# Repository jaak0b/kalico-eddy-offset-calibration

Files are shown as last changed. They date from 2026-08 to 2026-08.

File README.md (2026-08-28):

# eddy_tool_calibration 

A Kalico and Klipper plugin that accurately measures per-tool XYZ nozzle offsets on a toolchanger, even when the nozzle is dirty.

Uses a bed-mounted LDC1612 eddy-current coil (e.g. BTT Eddy Coil/Duo/USB or a Cartographer flashed with Klipper firmware).

A calibration run on my printer (https://www.youtube.com/watch?v=lr-eFiMrt0E)

## What you need

- A toolchanger running Kalico or Klipper.
- An LDC1612 board (e.g. BTT Eddy Coil/Duo/Usb or Cartographer flashed with Klipper firmware) mounted to the bed, coil facing up.
- For Z offsets: a contact switch (sexbolt, sexball, any fixed Z endstop).
- Your own toolchange and offset-apply gcode to change tools and apply offsets. This plugin is universal and it is not targeting any specific toolchange plugin.

## How accurate is it?

These numbers come from my printer, a Voron 2.4 with StealthChanger and a BTT
Eddy Coil, measured with `EDDY_REPEATABILITY`.

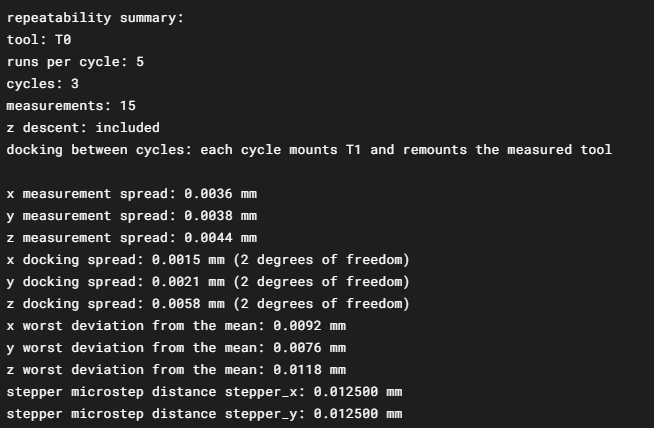
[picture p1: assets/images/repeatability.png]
Screenshot of EDDY_REPEATABILITY output


## Getting started

1. Wire up the eddy coil. See your probe's manual.
2. Mount the Eddy Coil Sensor to the bed with the coil facing up. [BTT Eddy Mount.stl](BTT%20Eddy%20Mount.stl) can be used for BTT Eddy probes.
3. Install the plugin, see [Install](#install).
4. Add the config, see [Required](#required).
5. Run [`EDDY_QUERY`](#commands) to check the wiring before anything moves.
6. Run [`LDC_CALIBRATE_DRIVE_CURRENT CHIP=eddy_tool_calibration`](#sensor-hardware). Only needed on non-BTT EDDY boards.
7. Jog the nozzle over the coil until the paper drags on the coil top face,
   then put the X, Y and Z position into `coil_x`, `coil_y` and
   `coil_z`.
8. Run [`EDDY_LOCATE`](#commands), and put the values into `coil_x` and `coil_y`.
9. For Z offsets (Optional): jog the nozzle over the contact switch (Sexball, Sexbolt or any other fixed mounted z homing switch), put those values
   into `switch_x`, `switch_y` and `switch_probe_z_start`, and set
   `calibrate_z: True`.
10. For Z offsets (Optional): Run [`EDDY_CALIBRATE_Z`](#commands) once per tool. Rerun it after a nozzle change.
11. Run [`EDDY_CALIBRATE_OFFSET`](#commands).
12. Run [`EDDY_REPEATABILITY T=0 RUNS=5 CYCLES=3`](#commands) to check the
    numbers are stable.

## Install

Requires Kalico or stock Klipper v0.13.0 or newer, an LDC1612 board
reachable over I2C (e.g. BTT Eddy Coil/Duo/Usb or Cartographer flashed with Klipper firmware) and Python 3 with no third-party packages.

```
cd ~
git clone https://github.com/jaak0b/kalico-eddy-offset-calibration
sh ~/kalico-eddy-offset-calibration/install.sh
sudo service klipper restart
```

Update manager entry for moonraker.conf:

```
[update_manager eddy_tool_calibration]
type: git_repo
path: ~/kalico-eddy-offset-calibration
origin: https://github.com/jaak0b/kalico-eddy-offset-calibration
primary_branch: main
is_system_service: False
```

## Config reference

Uncommented options are required and have no default, everything commented out may be left out. The blocks below are all parts of the same `[eddy_tool_calibration]` section.

### Required

```
[eddy_tool_calibration]
i2c_software_scl_pin:
i2c_software_sda_pin:
#   The SCL and SDA pins of the software i2c bus the LDC1612 chip is wired
#   to. This parameter must be provided.
coil_x:
coil_y:
#   Approximate machine X and Y (in mm) of the coil center. This parameter
#   must be provided.
coil_z:
#   Machine Z (in mm) of the coil top face. This parameter must be
#   provided.
coil_inner_diameter:
#   Bore (in mm) of the sensing coil. Must be greater than 0. It sets the
#   default fit_window_radius and scan_length. This parameter must be
#   provided.
```

### Toolchanger

Both tool_count and toolchange_gcode are needed only to run a calibration
command without T=. With toolchange_gcode set, both calibration commands
mount the tool they are about to work on, with T= as well as without it;
without it they work on whatever tool is already mounted. Every
non-baseline result is passed through apply_offsets_gcode as the run
proceeds.

```
#tool_count:
#   The number of tools on the machine, 1 to 16. Tools are T0 through
#   T(tool_count-1) with no gaps.
#toolchange_gcode:
#   The gcode that mounts a tool, as a template with {tool} bound to the
#   tool number.
#apply_offsets_gcode:
#   The gcode that applies a measured offset, as a template with {tool},
#   {offset_x} and {offset_y} bound, and {offset_z} bound as well when
#   calibrate_z is True. The default is to only report the offsets.
#tool_extruders:
#   Comma separated heater section names, one per tool, in tool number
#   order. Names are resolved at startup, so a name that does not exist is
#   a startup error. The default is to assume T0 uses extruder, T1 uses
#   extruder1 and so on.
```

### Z offset via the contact switch

> [!NOTE]
> Z offset means a tool's nozzle offset in Z relative to T0.

> [!IMPORTANT]
> The options below `calibrate_z` are ONLY required when `calibrate_z` is True.

> [!IMPORTANT]
> When `calibrate_z` is True, `EDDY_CALIBRATE_Z` must be run at least once, otherwise `EDDY_CALIBRATE_OFFSET` will refuse to measure the Z offset.

```
#calibrate_z: False
#   Set to True to measure Z. When set to True, `EDDY_CALIBRATE_Z` must be
#   run at least once.
#   The default is False.
switch_pin:
#   The endstop pin the contact switch is wired to. The switch itself is a plain
#   normally-open endstop switch; sexbolt and sexball style Z endstops work
#   well. The pin may be shared with an existing
#   [tools_calibrate] section.
#   This parameter must be provided.
switch_x:
#   The machine X position (in mm) the nozzle presses the switch at.
#   This parameter must be provided.
switch_y:
#   The machine Y position (in mm) the nozzle presses the switch at.
#   This parameter must be provided.
switch_probe_z_start:
#   The machine Z position (in mm) where each press starts from. Set it just above the
#   switch.
#   This parameter must be provided.
#switch_probe_speed: 5.0
#   Speed (in mm/s) of a downward press onto the switch. The default is
#   5.0mm/s.
#switch_probe_lift_speed:
#   Speed (in mm/s) of the retract between presses. The default is
#   switch_probe_speed.
#switch_probe_max_travel: 4.0
#   Distance (in mm) a press may travel down before the run is reported as
#   a missing trigger. The default is 4.0mm.
#switch_probe_sample_retract_dist: 2.0
#   Distance (in mm) the nozzle retracts after each press. Each press
#   starts from where the previous one retracted to, so this must be less
#   than switch_probe_max_travel. The default is 2.0mm.
#switch_probe_tolerance: 0.020
#   Distance (in mm) the three counted presses may disagree by before the
#   probing is reported as failed. The default is 0.020mm.
#calibration_temp: 150.0
#   Nozzle temperature (in Celsius) that every calibration measurement is
#   taken at. It must be above 0 when calibrate_z is True. The default is
#   150.0.
#calibration_temp_band: 2.0
#   Band (in Celsius) around the target temperature a nozzle has to read
#   within before the settle dwell starts. It applies both ways, so a tool
#   that has to cool only has to fall inside it. The default is 2.0.
#calibration_settle_time: 30.0
#   Dwell (in seconds) after a tool reaches the band, before measuring.
#   Both calibration commands dwell the same time, so both measure the
#   same thermal state. The default is 30.0 seconds.
#z_start: 2.5
#   Height (in mm) above the coil top face the downward Z move starts
#   from. The default is 2.5mm.
#z_stop: 0.5
#   Height (in mm) above the coil top face the downward Z move ends at.
#   Must be above the face, and below z_start. The default is 0.5mm.
#z_step: 0.05
#   Step size (in mm) of the downward Z move. Must be greater than 0, and
#   must divide the span from z_start to z_stop into a whole number of
#   steps. The default is 0.05mm.
```

### Sensor hardware

```
#i2c_address:
#i2c_mcu:
#i2c_bus:
#i2c_speed:
#   The remaining i2c settings for the LDC1612 chip. See the "common I2C
#   settings" section of Kalico's Config_Reference.md for a description of
#   these parameters. The chip's factory address is 42 decimal (0x2A).
#intb_pin:
#   The MCU gpio pin connected to the LDC1612 sensor's INTB pin, if it is
#   broken out. The default is to not use the INTB pin.
#frequency:
#   The external clock frequency (in Hz) fed to the LDC1612 CLKIN pin,
#   accepted from 2000000 to 40000000. It requires Kalico from March 2026,
#   or stock Klipper. The default is 12000000, which is correct for the
#   BTT Eddy family.
#reg_drive_current:
#   The LDC1612 DRIVE_CURRENT0 register value, 0 to 31. The default is 15,
#   which suits the BTT Eddy coil probe. For any other coil determine the right value with
#   `LDC_CALIBRATE_DRIVE_CURRENT CHIP=eddy_tool_calibration` and store the
#   printed value with SAVE_CONFIG. If a scan fails with a sensor
#   amplitude error ("Eddy current sensor error"), raise this value by one
#   and retry.
```

### Scan and fit tuning

```
#scan_height: 1.0
#   Height (in mm) above the coil top face the XY scan passes run at. Must
#   be above the face and below z_start. The default is 1.0mm.
#scan_safe_z: 2.0
#   Extra clearance (in mm) added above the scan height for travel moves.
#   Must be greater than 0. The default is 2.0mm.
#scan_speed: 4.0
#   Speed (in mm/s) of an XY scan pass. Lower it if a pass returns fewer
#   than samples_min samples. The default is 4.0mm/s.
#scan_length:
#   Length (in mm) of an XY scan pass. The default is 1.5 times
#   coil_inner_diameter: 12.0 mm for the 8 mm BTT Eddy Coil bore, 3.0 mm
#   for the 2 mm Little Crab bore.
#locate_scan_length:
#   Length (in mm) of the coarse EDDY_LOCATE pass. The default is three
#   times scan_length.
#travel_speed: 100.0
#   Speed (in mm/s) of XY travel moves between passes. The default is
#   100.0mm/s.
#z_speed: 10.0
#   Speed (in mm/s) of every Z leg except the switch presses, which use
#   switch_probe_speed and switch_probe_lift_speed. The default is
#   10.0mm/s.
#scan_angles: 45, 135
#   Comma separated scan directions (in degrees), where 0 runs along X+
#   and 90 along Y+. Two directions at least 30 degrees apart are needed
#   to get both axes. A repeated angle is a config error, and so is a pair
#   of opposite angles when pair_scans is enabled. The default is 45, 135.
#pair_scans: True
#   Set to True to scan the opposite of every configured angle as well and
#   average each pair, which cancels the shift each pass picks up along the
#   direction it travels. Pairing doubles the number of passes. The default
#   is True.
#samples_min: 100
#   Minimum usable samples per scan pass, at least 3. A pass below it is
#   reported as an error. The default is 100.
#query_time: 0.5
#   Time (in seconds) EDDY_QUERY collects samples for, at the driver's
#   250 Hz rate (400 Hz on Klipper master). The default is 0.5 seconds,
#   about 125 samples.
#freq_min: 1000000.0
#   Frequency (in Hz) below which samples are discarded as startup or
#   noise readings. The default is 1000000.0.
#edge_margin: 0.15
#   Fraction of each pass treated as its edge, above 0 and below 0.5. The
#   edges are left out of the search for the peak, and are used to tell
#   whether the pass peaks up or down. The default is 0.15.
#fit_window_radius:
#   Half width (in mm) of the sample window either side of the peak that
#   the curve is fitted to. The default is half of coil_inner_diameter.
#fit_sigma_fraction: 0.5
#   Standard deviation of the fit's weighting, as a fraction of the fit
#   window. It makes samples near the peak count for more than samples at
#   the window's edge. The default is 0.5.
#fit_vertex_limit: 0.5
#   Maximum distance between the fitted peak and the peak sample, as a
#   fraction of the fit window. A fit landing beyond it is reported as
#   failed rather than pulled back into range. The default is 0.5.
#center_tolerance: 0.05
#   Distance (in mm) two consecutive rounds of an XY measurement may
#   differ by before the measurement stops and reports the last round's
#   center. Rounds that differ by more are followed by another refine
#   round. Must be greater than 0. The default is 0.05mm.
#max_rounds: 6
#   Most scan rounds, counting the coarse round, one XY measurement runs
#   before it is reported as not settled. At least 2. The default is 6.
```

### Logging

```
#save_history: True
#   Set to True to append every completed measurement of a tool to
#   history_T<n>.csv in log_dir: the UTC timestamp, the command, the
#   fitted center, the offsets, the session of the baseline they were
#   measured against, the Z crossing and the height where the switch
#   clicks, the nozzle temperature the run was held at, the nozzle reading
#   observed while it ran, and the sample count. The default is True.
#save_csv: False
#   Set to True to write every scan pass's raw samples to a CSV file for
#   offline review. The default is False.
#log_dir: EddyToolCalibration/logs
#   Directory the drift logs and the repeatability study files are written
#   to, read against the printer config directory unless it is an absolute
#   path. These are the durable record. The default is
#   EddyToolCalibration/logs.
#csv_dir: EddyToolCalibration/data
#   Directory the raw scan dumps of save_csv are written to, read against
#   the printer config directory unless it is an absolute path. These are
#   working files, meant to be cleared once they have been looked at. The
#   default is EddyToolCalibration/data.
```

### Integration with Klipper Toolchanger plugin

Append the following config reference to `[eddy_tool_calibration]` for integration with [viesturz's klipper-toolchanger](https://github.com/viesturz/klipper-toolchanger)
```ini
toolchange_gcode:
    T{tool}
apply_offsets_gcode:
    SET_TOOL_PARAMETER T={tool} PARAMETER=gcode_x_offset VALUE={offset_x}
    SET_TOOL_PARAMETER T={tool} PARAMETER=gcode_y_offset VALUE={offset_y}
    SET_TOOL_PARAMETER T={tool} PARAMETER=gcode_z_offset VALUE={offset_z}
```

Append the following config reference to `[eddy_tool_calibration]` for integration with [klipper-toolchanger-hard](https://github.com/Contomo/klipper-toolchanger-hard)
```ini
toolchange_gcode:
    T{tool}
apply_offsets_gcode:
    SET_TOOL_OFFSET T={tool} X={offset_x} Y={offset_y} Z={offset_z}
```

## Supported hardware

Any eddy style probe with an LDC1612 works as long as it is flashed with stock Klipper firmware and reachable over I2C.

| Board |  |
|---|---|
| BTT Eddy Coil | Conected directly to the mainboard or a toolheadboard |
| BTT Eddy USB | Expected to work unmodified; I have not tried one. Its RP2040 runs standard Klipper firmware as a second MCU |
| BTT Eddy Duo | Expected to work in USB mode only. |
| [chengxg "Little Crab" dual-coil board](https://oshwhub.com/cxg01/project_lbabffjk) | The board this plugin's algorithm comes from; a sharper XY signal than the BTT coils. Mine are still being assembled, so unmeasured here |
| Cartographer | Only works if the board is flashed with Klipper firmware. Cartographer's own firmware will not work |

### BTT Eddy Coil

```ini
[eddy_tool_calibration]
i2c_mcu: mcu
i2c_software_scl_pin: 
i2c_software_sda_pin: 
i2c_address: 42
reg_drive_current: 15
coil_inner_diameter: 8.0
```

### BTT Eddy USB/DUO

```ini
[mcu eddy]
serial: /dev/serial/by-id/usb-Klipper_rp2040_XXXXXXXXXXXX-if00

[eddy_tool_calibration]
i2c_mcu: eddy
i2c_bus: i2c0f
i2c_software_scl_pin: 
i2c_software_sda_pin: 
i2c_address: 
reg_drive_current: 15
coil_inner_diameter: 8.0
```

### Little Crab

```ini
[eddy_tool_calibration]
i2c_mcu: mcu
i2c_software_scl_pin: 
i2c_software_sda_pin: 
frequency: 40000000
coil_inner_diameter: 2.0
reg_drive_current: 22
i2c_speed: 400000
i2c_address: 42
scan_speed: 4.0
scan_length: 4.0

```

Sources: [upstream repository](https://github.com/chengxg/tool_eddy_calibration),
[EasyEDA project](https://oshwhub.com/cxg01/project_lbabffjk).

## Commands

> [!NOTE]
> `T=` takes one tool number or a comma separated list with no spaces (`T=0,1,2`). Leaving `T=` out runs every tool and needs `tool_count`; any run covering more than one tool needs `toolchange_gcode`.

### EDDY_QUERY

`EDDY_QUERY`: Print statistics of the sensor frequency over `query_time` seconds without motion. Use it as a wiring check.

### LDC_CALIBRATE_DRIVE_CURRENT

`LDC_CALIBRATE_DRIVE_CURRENT CHIP=eddy_tool_calibration` prints the correct `reg_drive_current` for the connected sensor.

### EDDY_LOCATE
`EDDY_LOCATE [DEBUG=1]`: Measures the coil center precisely and stages it as `coil_x` and `coil_y`.

### EDDY_CALIBRATE_Z

> [!NOTE]
> Requires `calibrate_z: True`

`EDDY_CALIBRATE_Z [T=<list>] [DEBUG=1]`: Correlates the sensor's readings with the nozzle's actual Z height using a z endstop/microswitch.

Must be run once per tool. Rerun the command when the toolhead (e.g. the nozzle, hotend) changes.

Results are written to calibration_state.json directly.

### EDDY_CALIBRATE_OFFSET

> [!NOTE]
> T0 is always measured after a Klipper restart. 

`EDDY_CALIBRATE_OFFSET [T=<list>] [DEBUG=1]`: Measure the listed tools offset relative to T0. Prints the offset in the console. Runs `apply_offsets_gcode` when provided. 

### EDDY_REPEATABILITY

`EDDY_REPEATABILITY T=<tool> RUNS=<n> CYCLES=<n> [SKIP_Z=1] [DEBUG=1]`: Measures offset calibration repeatedly.
`RUNS=<n>` measurements taken back to back without touching the tool. Shows the measurement's own noise.
`CYCLES=<n>` how many times to swap the tool away and back before taking another set of runs, needs tool_count and toolchange_gcode, without them nothing is docked and the summary says so.
`SKIP_Z=0` measures Z as well, and needs the tool's EDDY_CALIBRATE_Z result. The default is 1, XY only.

## Reading the results from a macro

The plugin publishes `printer.eddy_tool_calibration` (keys are tool
numbers as decimal strings):

```jinja
{% set eddy = printer.eddy_tool_calibration %}
{% if eddy.tools['1'] is defined and eddy.tools['1'].offset_x is not none %}
  SET_GCODE_OFFSET X={eddy.tools['1'].offset_x} Y={eddy.tools['1'].offset_y}
{% endif %}
```

| Key | Meaning |
|---|---|
| `calibrate_z`, `tool_count` | the config section's values; `tool_count` `null` when unset |
| `baseline_tool` | tool the offsets are measured against, `null` until a baseline exists |
| `session_id` | rises by one each time a baseline replaces the previous one |
| `anchors` | what EDDY_CALIBRATE_Z stored, per tool; survives a restart. Each carries `anchor_height` (mm above the height where the switch clicks), `anchor_frequency` (Hz), `setpoint_temperature` (the temperature later runs heat to), `observed_temperature`, `trigger_z` (machine Z where the switch clicks) and `updated` (UTC) |
| `tools` | this session's measurements; a baseline replacement removes the measurements compared against the old one, so an offset here is never compared against a baseline that has moved. Each carries `offset_x/y/z` (mm; all `null` for the baseline itself, `offset_z` `null` when Z was not measured, and a `null` is never a zero), `center_x/y` (machine coordinates), `z_crossing` (machine Z where the downward move reached `anchor_frequency`), `session_id` and `measured_time` (host monotonic clock) |

## Measuring before each print

> [!IMPORTANT]
> Requires all [Toolchanger](#toolchanger) config options to be set.

> [!IMPORTANT]
> The macro assumes that your slicer passes tool temperature as `{if is_extruder_used[0]}T0_TEMP={first_layer_temperature[0]}{endif}` (Example for T0, use 1 for T1, 2 for T2,..) in your slicers machine start-gcode.

To calibrate each used tool before a print use the below macro and call `EDDY_CALIBRATE_USED_TOOLS {rawparams}` from your print_start macro.

```
[gcode_macro EDDY_CALIBRATE_USED_TOOLS]
description: Calibrate offsets for the tools this print actually uses
gcode:
    {% set sx = printer.toolhead.position.x %}
    {% set sy = printer.toolhead.position.y %}
    {% set sz = printer.toolhead.position.z %}
    {% set used = [] %}
    {% for key in params %}
        {% if key.startswith('T') and key.endswith('_TEMP') and key[1:-5].isdigit() %}
            {% set _ = used.append(key[1:-5]|int) %}
        {% endif %}
    {% endfor %}
    {% if used|length > 1 %}
        {% set tools = ([0] + used)|unique|list|sort %}
        EDDY_CALIBRATE_OFFSET T={tools|join(',')}
        G28 Z 
    {% endif %}
    G90
    G1 X{sx} Y{sy} F6000
    G1 Z{sz} F1200
```

## License

GNU GPLv3, see [LICENSE](LICENSE). The algorithms are reimplemented from
chengxg's GPLv3
[`tool_eddy_calibration`](https://github.com/chengxg/tool_eddy_calibration)
rather than copied from it, which makes this a derivative work under the
same license. His original file is kept unmodified in `reference/`.

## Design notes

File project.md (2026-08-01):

# EddyNozzleProbe

Automatic XYZ nozzle offset calibration for a Voron toolchanger, using a bed-mounted
eddy-current sensor board. Works with dirty nozzles: the sensor sees only metal, molten
plastic is invisible to it. Target firmware: Kalico (Klipper fork) only.

## Concept

A stationary sensor board at the bed edge, coil facing up. Each tool's nozzle is scanned
above the coil; the LDC1612 inductance-to-digital chip measures the resonant frequency
shift caused by the metal nozzle.

- **XY offset:** scan the nozzle across the coil, fit the symmetric response curve, take
  the symmetry center. Material-independent (brass, steel, plated copper all work) since
  it relies on geometry, not amplitude. Forward/reverse scans are averaged to cancel
  latency bias.
- **Z offset:** descend over the coil center, find where frequency crosses a per-tool
  calibrated reference. One-time contact calibration per tool material; automatic after.
- Claimed repeatability of the upstream project: 5 um same tool, ~20 um across tools.

## Hardware (ordered 2026-07-30, in transit)

Base design: chengxg's open-source "Little Crab" eddy XY calibration module
(GPLv3), dual-coil V2 board (2026-07 revision).

- Upstream repo: https://github.com/chengxg/tool_eddy_calibration
  (English fork: thunderkeys/tool_eddy_calibration, branch translate-en)
- oshwhub project (EasyEDA source): https://oshwhub.com/cxg01/project_lbabffjk
- Local verified copy: `E:\Development\crab-eddy-board\`: KiCad 10 import of the
  EasyEDA project (`kicad/crab_dualcoil.kicad_pcb|sch`), verified against the author's
  Gerbers by raster XOR (bottom copper 0.18% mismatch = render noise; top matches).
  Fab files: `gerber_dualcoil_v2.zip`, `BOM_dualcoil_v2.csv`, `CPL_dualcoil_v2.csv`.

### Board summary

LDC1612 (I2C, addr jumper, INTB broken out), 24 MHz 3225 active oscillator on CLKIN
(part labeled "40MHz" in author BOM/silkscreen but SMAF-024000 = 24.000 MHz; community
DigiKey BOM agrees on 24 MHz), SPX3819 3.3 V LDO fed by 5 V through 1N5819W, XH2.54-4P
connector (5V GND SCL SDA), two sensing channels:

- Channel 1 ("通道1"): small 5 mm 10 uH wound pancake coil (XKT-L111), hand-soldered.
  This is the XY/Z measurement coil (~2.3 MHz resonance with 470 pF C0G).
- Channel 2 ("通道2"): large spiral coil etched into the top copper. Reserved for future
  pressure-advance experiments; no firmware support yet. Unpopulated cap OK.

Board is 42.41 x 15.16 mm, all components on the bottom side, coils face up.
Two solder jumpers (J1 address, J2 I2C pullup enable) intentionally open.

### Orders placed

1. **JLCPCB:** 15 bare PCBs (black, 1.6 mm, LeadFree HASL, tented vias, flying probe)
   + bottom-side solder paste stencil (frameless). No assembly: self-assembly with
   hot air / hotplate. Stencil clarification answered: jumper/connector/coil pads stay
   closed on the stencil.
2. **DigiKey:** full parts kit for ~3 builds. Key parts: TI LDC1612DNTT x5,
   Abracon ASE-24.000MHZ-L-C-T (3.3 V LVCMOS 3225) x5, Samsung CL10C471JB8NNNC
   470 pF C0G x25 (performance-critical dielectric), Samsung CL10A106KP8NNNC 10 uF 10 V,
   SPX3819M5-L-3-3/TR x5, JST B4B-XH-A x5, 1k/4.7k 0603, LED, 1N5819W.
   Cart audited by two independent reviews against the author BOM; verdict OK.
   (100 nF: author used Y5V; X7R optional upgrade. SMD mounting nuts skipped: plain
   M3 hardware instead.)
3. **AliExpress:** XKT-L111 5 mm 10 uH pancake coils, 5-pack (channel-1 sensing coil).
   Enamel wire leads: burn/scrape insulation before soldering, glue coil body down.
4. **BTT Eddy Coil V1.0** (~19 EUR, arrives first): same electrical architecture
   (LDC1612 + coil, plain I2C, no MCU). Software development mule until crab boards
   are built. Bigger coil = worse XY sharpness, same driver and code paths.

### Assembly plan

Hotplate reflow with Sn42Bi58 low-temperature paste + stencil; hot air for rework.
LDC1612 (WSON-12, exposed pad) is the critical joint: paste amount on belly pad,
inspect with magnification. Practice run on a spare board first. 15 PCBs + 5 chips
allow multiple attempts.

## Electrical integration (printer side)

4 wires from board to any free MCU I2C-capable pins (software I2C fine): 5V, GND,
SCL, SDA. No MCU on the sensor board, nothing to flash. Kalico's standard MCU
firmware already contains I2C + ldc1612 support (re-flash mainboard only if its
firmware predates the ldc1612 driver).

Owner's printer: BTT Manta M8P V2.0 (STM32H723) with Raspberry Pi CM4 host.
Wiring plan: software I2C on the M8P V2.0 I2C connector pins PA8 (SCL) / PC9
(SDA), per the mainboard's own manual.

## Software (next phase)

Target: Kalico only. Upstream plugin `tool_eddy_calibration.py` (GPLv3, klippy extra)
does XY via directional scans + parabolic fitting; depends on stock `ldc1612.py`.
Kalico ships `ldc1612.py`, `probe_eddy_current.py`, and the improved `probe_eddy_ng`.
### Architecture decision (2026-07-30, fable-advisor verdict)

**Kalico plugin, no fork.** Kalico natively loads modules from the gitignored
`klippy/plugins/` directory (printer.py `_load_modules`, documented in
Kalico_Additions.md): full extras-equivalent API access, own git repo, symlink
install, moonraker update_manager for updates. Fork rejected: it worsens the
update-breakage risk (whole-tree rebases) and no MCU firmware changes are needed
(channel-1 big coil and >250 Hz sampling are speculative future work; ~60
samples/mm at 4 mm/s scans suffices for parabolic fitting). Revisit forking only
if firmware changes become real.

**Own unified plugin (owner decision 2026-07-30, supersedes the vendoring
layout):** one plugin covering XY and Z with a single config section
(`[eddy_tool_calibration]`) and one command set. We port the upstream
algorithm (directional scans, parabolic sub-sample fit, forward/reverse pair
cancellation) rather than vendoring his code; his file stays in-repo as
reference and future upstream improvements are ported as ideas, not diffs.
Consequences: plugin is GPLv3 (derivative of upstream), and first-run
validation burden is ours (covered by the BTT Eddy Coil dev period).
Sample-to-position sync uses motion_report.get_trapq_position instead of
upstream's constant-speed interpolation.

**Offset output: console only for now.** Owner runs StealthChanger today but
is moving to a cxchanger (hotend-swap) toolchanger with possibly its own
plugin later; persistence/toolchanger integration deliberately deferred.
Plugin prints computed per-tool XYZ offsets as labeled values; the user
transfers them manually. save_variables/SAVE_CONFIG hooks are future work.

**Kalico pieces to build on** (verified in source at Kalico 5fdf0dd):
- `ldc1612.py`: 250 Hz batch streaming of (print_time, freq) via `add_client`,
  configurable CLKIN (`frequency: 24000000` for our board), software I2C,
  `LDC_CALIBRATE_DRIVE_CURRENT`.
- `motion_report.get_trapq_position(print_time)`: exact commanded position at a
  sample timestamp; upgrade over upstream's constant-speed linear interpolation.
- `probe_eddy_current.py` `EddyCalibration`: freq<->Z piecewise mapping +
  step-dwell calibration move pattern for per-tool Z references.
- `tools_calibrate.py` (bundled viesturz contact calibration): persistence
  template (`configfile.set` + SAVE_CONFIG, or save_variables) and a cross-check
  oracle against the contact-pin method.
- `SET_GCODE_OFFSET` in gcode_move.py for applying offsets at runtime.

Maintenance rule: pin upstream SHA; after each Kalico update run a smoke
calibration (API breakage surfaces at runtime, not load time).

### Hardware validation (2026-08-01)

First hardware validation day, BTT Eddy Coil on a Manta M8P V2.0, Voron printer
with StealthChanger, nozzles at 150 C.

- EDDY_QUERY noise floor: stddev ~58 Hz at 3.216 MHz base frequency.
- XY repeatability, six EDDY_CALIBRATE runs on T0 without toolchange: stddev
  4.6 um X, 2.5 um Y (ranges 12.2 um X, 6.9 um Y).
- T1 offset repeatability across four runs, including one full dock/redock:
  range 12 um X, 11 um Y.
- Switch press spread per anchor run: 2.5 um (T0), 0.0 um (T1).
- Cross-check against a fresh contact calibration (the toolchanger's own
  routine, same day, 150 C): X within 22 to 66 um, Y within 46 um. Sign
  convention verified, offsets match the toolchanger's gcode offset
  convention directly.
- Trapq position-mapping bug found and fixed on hardware day: samples were
  mapped to scan-start position mid-move; fixed by mapping after the move
  completes.
- Z descent monotonicity requires a z_start of 2.5 mm (sensor range limit is
  roughly 2 to 3 mm).

## Decisions log

- Eddy current sensing chosen over contact pin (dirty-nozzle immunity) and optical
  (sees plastic drool). 2026-07-30.
- Geometry-over-amplitude principle: mixed nozzle materials make absolute amplitude
  untrustworthy; only symmetry centers and calibrated references are used.
- Buy + adapt upstream Little Crab design instead of designing a custom board;
  BTT Eddy hardware rejected as primary (coil too large for XY sharpness) but used
  as an interim dev unit.
- 24 MHz oscillator variant ordered (community-validated) despite "40MHz" labels;
  scale-free math and calibration absorb the constant either way.

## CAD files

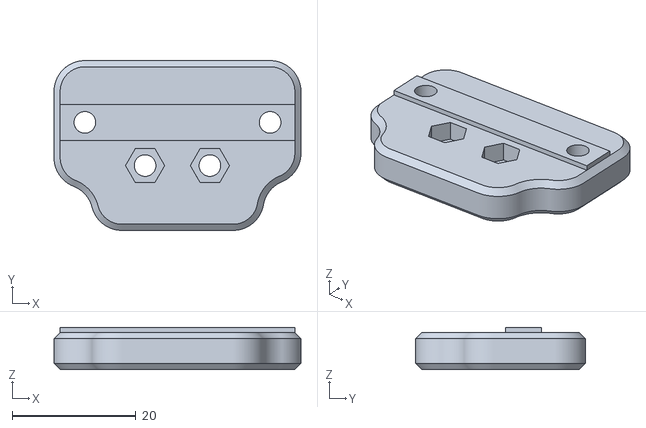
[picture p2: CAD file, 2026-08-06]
BTT Eddy Mount.stl
40.0 x 27.5 x 6.80

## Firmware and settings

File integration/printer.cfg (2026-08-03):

# Printer config for the integration tests. Nothing here describes real
# hardware: the MCU is the firmware's linuxprocess simulation target and the
# pin names are that target's own, so the numbers are placeholders chosen only
# to pass config validation. The harness appends kalico_overlay.cfg to this
# file on a Kalico checkout.

[mcu]
serial: /tmp/klipper_host_mcu

[printer]
kinematics: cartesian
max_velocity: 300
max_accel: 3000
max_z_velocity: 15
max_z_accel: 100

[stepper_x]
step_pin: gpio0
dir_pin: gpio1
enable_pin: !gpio2
microsteps: 16
rotation_distance: 40
endstop_pin: ^gpio3
position_endstop: 0
position_max: 400
homing_speed: 50

[stepper_y]
step_pin: gpio4
dir_pin: gpio5
enable_pin: !gpio6
microsteps: 16
rotation_distance: 40
endstop_pin: ^gpio7
position_endstop: 0
position_max: 400
homing_speed: 50

[stepper_z]
step_pin: gpio8
dir_pin: gpio9
enable_pin: !gpio10
microsteps: 16
rotation_distance: 8
endstop_pin: ^gpio11
position_endstop: 0
position_max: 300
homing_speed: 10

[extruder]
step_pin: gpio12
dir_pin: gpio13
enable_pin: !gpio14
microsteps: 16
rotation_distance: 22.6789511
nozzle_diameter: 0.400
filament_diameter: 1.750
heater_pin: gpio15
sensor_type: Generic 3950
sensor_pin: analog0
control: watermark
min_temp: 0
max_temp: 300

[extruder1]
step_pin: gpio16
dir_pin: gpio17
enable_pin: !gpio18
microsteps: 16
rotation_distance: 22.6789511
nozzle_diameter: 0.400
filament_diameter: 1.750
heater_pin: gpio19
sensor_type: Generic 3950
sensor_pin: analog1
control: watermark
min_temp: 0
max_temp: 300

# toolchange_gcode below renders to T0 or T1, so those commands have to exist
# the way they do on a toolchanger.
[gcode_macro T0]
gcode:
    ACTIVATE_EXTRUDER EXTRUDER=extruder

[gcode_macro T1]
gcode:
    ACTIVATE_EXTRUDER EXTRUDER=extruder1

[eddy_tool_calibration]
i2c_mcu: mcu
i2c_software_scl_pin: gpio20
i2c_software_sda_pin: gpio21
i2c_address: 42
# frequency is left out on purpose. Kalico's ldc1612 driver gained that
# option in March 2026, and an option no module read is a startup error, so
# setting it here would restrict this test to builds from then on.
reg_drive_current: 15
coil_x: 200.0
coil_y: 20.0
coil_z: 0.0
coil_inner_diameter: 2.0
scan_height: 1.0
scan_safe_z: 2.0
z_start: 2.5
z_stop: 0.5
z_step: 0.05
scan_angles: 45, 135
pair_scans: True
calibrate_z: True
switch_pin: ^gpio22
switch_x: 190.0
switch_y: 20.0
switch_probe_z_start: 3.0
calibration_temp: 150.0
tool_count: 2
toolchange_gcode:
    T{tool}
apply_offsets_gcode:
    SET_GCODE_OFFSET X={offset_x} Y={offset_y} Z={offset_z}

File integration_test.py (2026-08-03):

#!/usr/bin/env python3
# Copyright (C) 2026  Jakob
#
# This file may be distributed under the terms of the GNU GPLv3 license.
import argparse
import contextlib
import os
import shutil
import subprocess
import sys
import tempfile
from pathlib import Path

REPO_DIR = Path(__file__).resolve().parent
PLUGIN_SRC = REPO_DIR / 'eddy_tool_calibration.py'
CASE_DIR = REPO_DIR / 'integration'

# The linuxprocess target builds with the host compiler in every supported
# firmware, so no cross-toolchain is needed for the simulated MCU the cases
# run against.
MCU_TARGET = 'linuxprocess'
DICT_NAME = '%s.dict' % (MCU_TARGET,)

CASE_TIMEOUT = 600.0

# Kalico scripts/test_klippy.py:13, Klipper scripts/test_klippy.py:9: both
# harnesses give klippy a log file of this name relative to their own working
# directory, unless they were asked for verbose output: then klippy has no
# log file and Python's fallback handler puts only warnings and worse on
# stderr, well above the level the markers below are logged at.
KLIPPY_LOG = '_test_.log'

# What the harness does differently per firmware layout, one row per
# divergent surface, mirroring the markers install.sh detects with.
# chelper: Kalico ships klippy/__init__.py, so its C helper imports as
# klippy.chelper from the checkout root; stock Klipper has no such package
# and chelper imports from the klippy/ directory itself.
# link_klippy_tree: stock test_klippy.py launches './klippy/klippy.py'
# relative to its working directory (scripts/test_klippy.py:94 on master),
# and the klippy log stays per-case only when that directory is the case's
# own, so each case directory gets a symlink to the checkout's klippy tree.
LAYOUTS = {
    'kalico': {
        'install_dir': ('klippy', 'plugins'),
        'create_package_marker': True,
        'chelper_code': 'import klippy.chelper; klippy.chelper.get_ffi()',
        'chelper_cwd': (),
        'config_overlay': 'kalico_overlay.cfg',
        'link_klippy_tree': False,
    },
    'klipper': {
        'install_dir': ('klippy', 'extras'),
        'create_package_marker': False,
        'chelper_code': 'import chelper; chelper.get_ffi()',
        'chelper_cwd': ('klippy',),
        'config_overlay': None,
        'link_klippy_tree': True,
    },
}

# Klipper's gcode dispatcher catches CommandError and nothing else, so any
# other exception is logged with a traceback and shuts the printer down.
# Whatever the case expects, none of these may appear.
FORBIDDEN_ALWAYS = (
    'Traceback (most recent call last)',
    'Unhandled exception',
    'Internal error',
)

# Klipper master klippy/util.py:54-61 (_try_read_file): the startup probe of
# /proc/device-tree/model catches IOError/OSError, logs it at debug level with
# a full traceback under this prefix, and returns None; get_device_info
# (util.py:127) falls back and klippy continues. On hosts without that file
# the traceback is routine, so it alone must not trip FORBIDDEN_ALWAYS.
BENIGN_TRACEBACK_PREFIX = 'Exception on read /proc/device-tree/model:'


def strip_benign_traceback(output):
    lines = output.splitlines(keepends=True)
    kept = []
    i = 0
    while i < len(lines):
        if not lines[i].startswith(BENIGN_TRACEBACK_PREFIX):
            kept.append(lines[i])
            i += 1
            continue
        i += 1
        while i < len(lines) and lines[i][:1] in (' ', '\t'):
            i += 1
        if i < len(lines) and lines[i].startswith('FileNotFoundError'):
            i += 1
    return ''.join(kept)


HOME_FIRST = 'Home the printer first.'

# The plugin reports this for the first press of a debug run, so it appears
# only once a probing move has run through the plugin's endstop object and
# returned a trigger position.
SWITCH_PRESSED = 'switch press 1 trigger (machine Z):'

# klippy logs this once every config section has been built and the connect
# handlers are running, so it is what says the plugin's section survived
# config load. The gcode of a case runs only after it.
CONNECTED = "Sending MCU 'mcu' printer configuration..."

CASES = (
    {
        'name': 'config load',
        'test': 'config_load.test',
        'require': (CONNECTED,),
        'forbid': (),
    },
    {
        'name': 'EDDY_LOCATE',
        'test': 'eddy_locate_unhomed.test',
        'require': (HOME_FIRST,),
        'forbid': ('Unknown command:"EDDY_LOCATE"',),
    },
    {
        'name': 'EDDY_CALIBRATE_Z',
        'test': 'eddy_calibrate_z_unhomed.test',
        'require': (HOME_FIRST,),
        'forbid': ('Unknown command:"EDDY_CALIBRATE_Z"',),
    },
    {
        'name': 'EDDY_CALIBRATE_Z homed',
        'test': 'eddy_calibrate_z_homed.test',
        'require': (SWITCH_PRESSED,),
        'forbid': (),
    },
    {
        'name': 'EDDY_CALIBRATE_OFFSET',
        'test': 'eddy_calibrate_offset_unhomed.test',
        'require': (HOME_FIRST,),
        'forbid': ('Unknown command:"EDDY_CALIBRATE_OFFSET"',),
    },
    {
        'name': 'EDDY_REPEATABILITY',
        'test': 'eddy_repeatability_unhomed.test',
        'require': (HOME_FIRST,),
        'forbid': ('Unknown command:"EDDY_REPEATABILITY"',),
    },
)


class Failure(Exception):
    pass


def report(line=''):
    sys.stdout.write(line + '\n')
    sys.stdout.flush()


def check_checkout(raw):
    checkout = Path(raw).expanduser().resolve()
    if not checkout.is_dir():
        raise Failure(
            "Firmware checkout not found: %s. Pass the directory holding "
            "the firmware's klippy/ and scripts/ directories." % (checkout,))
    needed = [
        checkout / 'klippy',
        checkout / 'scripts' / 'test_klippy.py',
        checkout / 'test' / 'configs' / ('%s.config' % (MCU_TARGET,)),
        checkout / 'Makefile',
    ]
    missing = [str(p) for p in needed if not p.exists()]
    if missing:
        raise Failure(
            "%s does not look like a Kalico or Klipper checkout. Missing: %s."
            % (checkout, ", ".join(missing)))
    return checkout


def detect_layout(checkout):
    """Name the firmware layout of a checkout, from the LAYOUTS closed set."""
    # Kalico's module loader is klippy/printer.py scanning "klippy.plugins."
    # (printer.py:194 on development, :282 at 3b98cf51); the plugins
    # directory itself may not exist yet in a fresh checkout. Stock Klipper
    # has no printer.py and klippy/klippy.py:90-103 loads only from
    # klippy/extras/.
    printer_py = checkout / 'klippy' / 'printer.py'
    if (printer_py.is_file()
            and 'klippy.plugins' in printer_py.read_text(errors='replace')):
        return 'kalico'
    if ((checkout / 'klippy' / 'klippy.py').is_file()
            and (checkout / 'klippy' / 'extras').is_dir()):
        return 'klipper'
    raise Failure(
        "%s is neither a Kalico nor a stock Klipper checkout: it has no "
        "klippy/printer.py loading klippy.plugins, and no klippy/klippy.py "
        "with a klippy/extras/ directory." % (checkout,))


def run_tool(command, cwd, env, what):
    try:
        proc = subprocess.run(
            command, cwd=str(cwd), env=env, text=True,
            stdout=subprocess.PIPE, stderr=subprocess.STDOUT)
    except OSError as e:
        raise Failure("%s could not be started: %s." % (what, e))
    if proc.returncode != 0:
        raise Failure(
            "%s failed with exit code %d.\n%s"
            % (what, proc.returncode, proc.stdout))
    return proc.stdout


def build_dictionary(checkout, build_dir, dictdir):
    """Build the MCU dictionary the cases run against from this checkout.

    The dictionary carries the command set of the firmware, so it has to come
    from the same checkout as klippy: a dictionary built elsewhere would test
    the plugin against a protocol that checkout does not speak.
    """
    source = checkout / 'test' / 'configs' / ('%s.config' % (MCU_TARGET,))
    build_dir.mkdir(parents=True, exist_ok=True)
    config = build_dir / '.config'
    shutil.copyfile(str(source), str(config))
    # The Makefile joins OUT with relative paths, so it has to end in a
    # separator, and it keeps the build out of the checkout's own out/.
    make = [
        'make', '-C', str(checkout),
        'OUT=%s%s' % (build_dir, os.sep),
        'KCONFIG_CONFIG=%s' % (config,),
    ]
    env = os.environ.copy()
    try:
        run_tool(make + ['olddefconfig'], checkout, env,
                 'The firmware configure')
        run_tool(make, checkout, env, 'The firmware build')
    except Failure as e:
        raise Failure(
            "%s\nThe %s firmware is built with make and the host C compiler. "
            "Install both, or point --dictdir at a directory that already "
            "holds %s." % (e, MCU_TARGET, DICT_NAME))
    built = build_dir / 'klipper.dict'
    if not built.is_file():
        raise Failure(
            "The firmware build produced no %s. The build writes the "
            "dictionary next to klipper.elf; check the build output above."
            % (built,))
    dictdir.mkdir(parents=True, exist_ok=True)
    shutil.copyfile(str(built), str(dictdir / DICT_NAME))


def build_chelper(checkout, env, layout):
    """Compile klippy's C helper before any case runs.

    Kalico's own test/conftest.py calls chelper.get_ffi() at session start for
    the same reason: the first import compiles c_helper.so, and a compiler or
    dependency problem there would otherwise be reported as a failing case.
    """
    spec = LAYOUTS[layout]
    try:
        run_tool(
            [sys.executable, '-c', spec['chelper_code']],
            checkout.joinpath(*spec['chelper_cwd']), env,
            "Building klippy's C helper")
    except Failure as e:
        raise Failure(
            "%s\nklippy needs a C compiler and its Python dependencies "
            "(cffi, greenlet, Jinja2, numpy, pyserial). Install them into "
            "%s, the interpreter running this script."
            % (e, sys.executable))


def link_plugin(target):
    try:
        os.symlink(str(PLUGIN_SRC), str(target))
        return 'symlink'
    except OSError as symlink_error:
        try:
            shutil.copyfile(str(PLUGIN_SRC), str(target))
        except OSError as copy_error:
            raise Failure(
                "Could not install the plugin at %s. The symlink failed with "
                "%s and the copy failed with %s. Check the write permissions "
                "on that directory." % (target, symlink_error, copy_error))
        return 'copy'


@contextlib.contextmanager
def installed_plugin(checkout, layout):
    spec = LAYOUTS[layout]
    plugins_dir = checkout.joinpath(*spec['install_dir'])
    target = plugins_dir / PLUGIN_SRC.name
    package_marker = plugins_dir / '__init__.py'
    created_dir = created_marker = False
    backup = None
    if not plugins_dir.is_dir():
        plugins_dir.mkdir(parents=True)
        created_dir = True
    if spec['create_package_marker'] and not package_marker.exists():
        package_marker.touch()
        created_marker = True
    already_installed = False
    if target.is_symlink() or target.exists():
        if target.resolve() == PLUGIN_SRC:
            already_installed = True
        else:
            backup = plugins_dir / (target.name + '.integration-backup')
            if backup.exists():
                raise Failure(
                    "%s already exists. A previous run left it behind: move "
                    "the file you want to keep back to %s and delete the "
                    "other one." % (backup, target))
            os.replace(str(target), str(backup))
    try:
        if already_installed:
            report('plugin: already installed at %s' % (target,))
        else:
            report('plugin: installed at %s by %s'
                   % (target, link_plugin(target)))
        yield
    finally:
        if not already_installed and (target.is_symlink() or target.exists()):
            target.unlink()
        if backup is not None:
            os.replace(str(backup), str(target))
        cache = plugins_dir / '__pycache__'
        if cache.is_dir():
            shutil.rmtree(str(cache), ignore_errors=True)
        if created_marker and package_marker.exists():
            package_marker.unlink()
        if created_dir:
            try:
                plugins_dir.rmdir()
            except OSError as e:
                report('note: %s was created by this run and could not be '
                       'removed: %s' % (plugins_dir, e))


def case_output(case_dir, harness_output):
    """Everything one case produced: what the firmware's harness printed,
    plus the klippy log it kept. That harness prints the log itself when a
    run defied the case's expectation, so it is appended only when it is not
    there yet.
    """
    # On a timeout subprocess hands back bytes even in text mode
    # (TimeoutExpired.output is never decoded), so the markers would
    # otherwise be compared against bytes and raise instead of reporting.
    if isinstance(harness_output, bytes):
        harness_output = harness_output.decode('utf-8', errors='replace')
    output = harness_output or ''
    log_path = case_dir / KLIPPY_LOG
    if not log_path.is_file():
        return output + '\n%s was never written.\n' % (log_path,)
    log = log_path.read_text(errors='replace')
    if log in output:
        return output
    return output + log


def stage_cases(scratch, layout):
    """Copy the cases where they can sit next to the composed printer.cfg."""
    staged = scratch / 'cases'
    staged.mkdir()
    for case in CASES:
        shutil.copyfile(str(CASE_DIR / case['test']),
                        str(staged / case['test']))
    config = (CASE_DIR / 'printer.cfg').read_text()
    overlay = LAYOUTS[layout]['config_overlay']
    if overlay is not None:
        config += (CASE_DIR / overlay).read_text()
    (staged / 'printer.cfg').write_text(config)
    return staged


def run_case(case, checkout, staged, dictdir, workdir, env, layout):
    """Run one case through the firmware's harness. Returns (problems,
    output)."""
    # klippy appends to its log file and the name above is the same for every
    # case, so each case runs in a directory of its own.
    case_dir = workdir / case['test']
    case_dir.mkdir(parents=True, exist_ok=True)
    if LAYOUTS[layout]['link_klippy_tree']:
        tree_link = case_dir / 'klippy'
        if not tree_link.exists():
            try:
                os.symlink(str(checkout / 'klippy'), str(tree_link))
            except OSError as e:
                return (["the klippy tree could not be linked into %s: %s"
                         % (case_dir, e)], '')
    command = [
        sys.executable, str(checkout / 'scripts' / 'test_klippy.py'),
        '-k', '-d', str(dictdir), '-t', '.', str(staged / case['test']),
    ]
    try:
        proc = subprocess.run(
            command, cwd=str(case_dir), env=env, text=True,
            stdout=subprocess.PIPE, stderr=subprocess.STDOUT,
            timeout=CASE_TIMEOUT)
    except subprocess.TimeoutExpired as e:
        return (["the run did not finish within %.0f seconds"
                 % (CASE_TIMEOUT,)], case_output(case_dir, e.output))
    except OSError as e:
        return (["test_klippy.py could not be started: %s" % (e,)], '')
    output = case_output(case_dir, proc.stdout)
    checked = strip_benign_traceback(output)
    problems = []
    if proc.returncode != 0:
        problems.append(
            "test_klippy.py reported failure, exit code %d"
            % (proc.returncode,))
    for marker in case['require']:
        if marker not in output:
            problems.append("the expected output %r never appeared" % (marker,))
    for marker in tuple(case['forbid']) + FORBIDDEN_ALWAYS:
        if marker in checked:
            problems.append("the output %r appeared" % (marker,))
    return problems, output


def run_cases(checkout, staged, dictdir, workdir, env, verbose, layout):
    failed = 0
    for case in CASES:
        problems, output = run_case(
            case, checkout, staged, dictdir, workdir, env, layout)
        if problems:
            failed += 1
            report('case %s: FAILED' % (case['name'],))
            for problem in problems:
                report('    %s' % (problem,))
        else:
            report('case %s: passed' % (case['name'],))
        if problems or verbose:
            report('--- output of %s ---' % (case['test'],))
            report(output.rstrip())
            report('--- end of output ---')
    report()
    report('cases run: %d' % (len(CASES),))
    report('cases failed: %d' % (failed,))
    return failed


def main():
    parser = argparse.ArgumentParser(
        description=(
            "Run the plugin's config section and its commands through the "
            "firmware's own regression harness against a Kalico or stock "
            "Klipper checkout. This is a separate entry point from the unit "
            "tests, because it needs a checkout, a C compiler and a POSIX "
            "host."))
    parser.add_argument(
        'checkout',
        help="path to the firmware checkout to test the plugin against")
    parser.add_argument(
        '--dictdir', default=None,
        help=("directory holding %s. It is built from the checkout when it is "
              "missing there. Without this option the dictionary is built into "
              "a temporary directory on every run." % (DICT_NAME,)))
    parser.add_argument(
        '--verbose', action='store_true',
        help="print the klippy output of every case, not only failing ones")
    args = parser.parse_args()

    if os.name != 'posix':
        raise Failure(
            "klippy runs on POSIX hosts only: it needs fork and the termios "
            "module. Run this script on the printer host, or in a Linux "
            "virtual machine or container with the firmware checkout "
            "mounted.")
    if not PLUGIN_SRC.is_file():
        raise Failure(
            "cannot find %s. Run this script from its own repository."
            % (PLUGIN_SRC,))

    checkout = check_checkout(args.checkout)
    layout = detect_layout(checkout)
    report('firmware checkout: %s' % (checkout,))
    report('firmware layout: %s' % (layout,))
    report('python: %s' % (sys.executable,))

    env = os.environ.copy()
    existing = env.get('PYTHONPATH')
    env['PYTHONPATH'] = (
        str(checkout) if not existing
        else str(checkout) + os.pathsep + existing)

    with tempfile.TemporaryDirectory(prefix='eddy-integration-') as scratch:
        scratch = Path(scratch)
        if args.dictdir is None:
            dictdir = scratch / 'dict'
        else:
            dictdir = Path(args.dictdir).expanduser().resolve()
        if (dictdir / DICT_NAME).is_file():
            report('dictionary: %s, reused' % (dictdir / DICT_NAME,))
        else:
            build_dictionary(checkout, scratch / 'build', dictdir)
            report('dictionary: %s, built from this checkout'
                   % (dictdir / DICT_NAME,))
        build_chelper(checkout, env, layout)
        staged = stage_cases(scratch, layout)
        workdir = scratch / 'run'
        workdir.mkdir()
        report()
        with installed_plugin(checkout, layout):
            failed = run_cases(
                checkout, staged, dictdir, workdir, env, args.verbose, layout)
    return 1 if failed else 0


if __name__ == '__main__':
    try:
        sys.exit(main())
    except Failure as error:
        sys.stderr.write('integration_test.py: %s\n' % (error,))
        sys.exit(2)

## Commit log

2026-07-30 Fix the inherited det_b determinant bug, scan-window end-time capture, sensor client leaks, unsafe travel ordering, and the remaining review findings with regression tests.
    [eddy_tool_calibration.py]
2026-08-01 Resolve scan sample positions after the move completes because trapq history excludes the executing move.
    [eddy_tool_calibration.py]
2026-08-01 Write scan CSV dumps into a configurable subdirectory of the printer config folder.
2026-08-01 Print only the summary block by default, add a DEBUG parameter for per-pass rows, and label baseline-run offsets as zero by definition.
2026-08-01 Fold the baseline into EDDY_CALIBRATE_TOOL T=0 and gate the Z descent behind a z_offset_mode choice of identical or mixed hotends.
2026-08-01 Add switch-probed Z references with a plugin-managed state file and rename the calibration commands.
2026-08-01 Retreat the toolhead on every probing failure path and tighten switch travel validation.
    [eddy_tool_calibration.py]
2026-08-01 Add fleet sweeps, toolchange and offset templates, and tool_count to the calibration commands.
2026-08-01 Require setup-specific coil options, drop invented defaults from the config reference, and lower the z_start default to the sensor's usable range.
2026-08-01 Name the switch hardware for the Z reference in the command and config docs.
2026-08-01 Halve the introduction and show a real calibration run as the example output.
2026-08-01 Use Kalico's documented klipper checkout path in the install script and docs.
2026-08-01 Hold the nozzle at its calibration temperature, record it per tool, and accept tool lists with a single parallel preheat.
2026-08-01 Print machine step distances in the Z reference readout too.
2026-08-01 Fix the review findings across the repeatability study, the drift logs, and the measurement readouts.
    [eddy_tool_calibration.py]
2026-08-01 Tell the reader to restart the klipper service after installing or updating the plugin.
2026-08-01 Replace the run time estimate with a progress row printed before each measurement.
    [eddy_tool_calibration.py]
2026-08-01 Link a video of a calibration run from the README.
2026-08-01 Anchor the nozzle setpoint rather than an instantaneous reading and wait only for a temperature band.
2026-08-01 Take fault counts from the sample batches, drop guards Kalico already owns, and refuse an anchor whose sensor settings changed.
2026-08-01 Read the sensor count-to-hertz conversion in a way older Kalico builds also support.
2026-08-01 Record that the reference clone is newer than the target printer and that handler exceptions shut it down.
2026-08-01 Cut comments and command documentation down to what the code and the reader cannot supply.
2026-08-01 Extract the weighted quadratic solve, the post-move position mapping, the measurement publication, and the descent bucketing; rotate an outdated drift log instead of refusing it.
    [printer.cfg]
2026-08-01 Print one repeatability summary at the end of a study.
    [printer.cfg]
2026-08-01 Unify the offsets predicate, the sample count, the scan round loop, the fleet list and the numbered filename rule.
2026-08-01 Unify the sample window, the batch callback, the closed-set predicates, the anchor schema, the result record and the directory resolution.
2026-08-02 Give the readout rows, the drop fields, the switch heights and the angle helpers one home each.
2026-08-02 Make the retreat lift only, never lower the toolhead onto what it failed above.
    [eddy_tool_calibration.py]
2026-08-02 Give the duplicated closed-set errors, readout rows, guards and diagnosis blocks one home each.
    [eddy_tool_calibration.py]
2026-08-02 Set up the contact switch endstop in the plugin instead of borrowing another module's wrapper.
    [printer.cfg]
2026-08-02 Stamp each Z reference with the sensor clock instead of a conversion factor the fallback doubled.
2026-08-02 Resolve the firmware surfaces that differ between builds once at startup, each by inspecting what the build carries.
    [eddy_tool_calibration.py]
2026-08-03 Teach the install script, harness and CI which firmware layout a checkout carries.
    [kalico_overlay.cfg, printer.cfg]
2026-08-03 Document the second firmware, the sensor hardware verdicts and the dirty-nozzle result.
2026-08-03 Decode a timed-out case's output before matching markers against it.
2026-08-03 Say which Klipper versions work in the user's terms and cut the option history narration.
2026-08-03 Refuse to stream the sensor in a batch run, where no hardware can ever answer.
2026-08-03 Cut the README prose to half.
2026-08-03 Exempt Klipper's own logged device-tree probe traceback from the crash guard.
    [integration_test.py]
2026-08-03 Record the green four-leg matrix in the handover.
2026-08-03 Warn instead of raising when the drift log cannot be written, so a log failure never aborts a print.
    [eddy_tool_calibration.py]
2026-08-06 Rewrite the config option descriptions in Klipper's reference style.
2026-08-06 Rewrite the README, name the supported boards and add toolchanger integration snippets.
2026-08-06 Add a getting started sequence and the bed mount model.
    [BTT Eddy Mount.step]
2026-08-06 add eddy assembly cad model
    [BTT Eddy Mount.step, BTT Eddy Mount.stl]
2026-08-06 Stage the measured coil center for SAVE_CONFIG instead of printing it for hand copying.
2026-08-06 Tell the user SAVE_CONFIG is waiting, the way every other calibration command does.
2026-08-07 Fix typo in README.md for eddy style probe
2026-08-08 Modify calibration settings in README.md
    Updated frequency, drive current, and added I2C settings.
2026-08-22 Simplify the scan dump name collision check to a plain loop
    [eddy_tool_calibration.py]
2026-08-22 Save a scan pass before the sensor health check can reject it
2026-08-28 Shorten the baseline tool line in the offsets summary
    [eddy_tool_calibration.py]

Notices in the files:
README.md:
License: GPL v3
